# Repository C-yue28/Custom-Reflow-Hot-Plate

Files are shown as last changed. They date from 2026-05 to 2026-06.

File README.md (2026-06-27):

<h1>Custom Reflow Oven</h1>

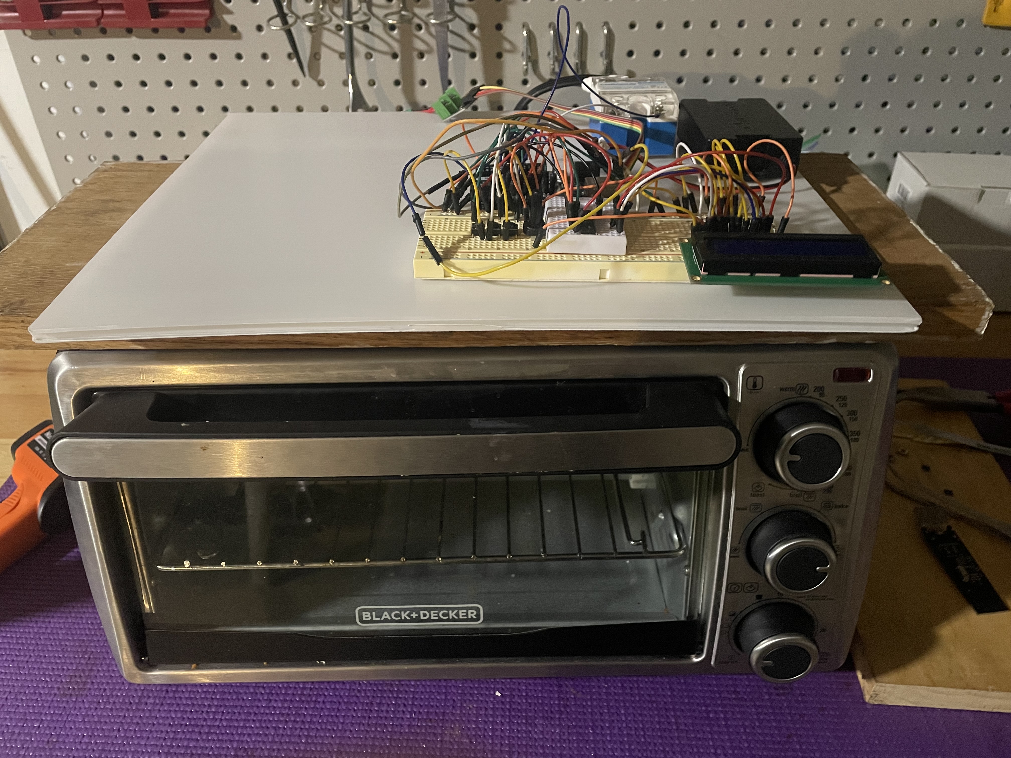
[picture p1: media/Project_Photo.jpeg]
Project Photo


<h3>Why did I make this?</h3>
<p>Designing and purchasing custom PCBs is expensive. For reference, my first custom devboard was quoted by JLCPCB at around $180, and almost 75% of that was due to assembly costs. Therefore, I sought to cut costs by designing my own at-home PCB assembly system, beginning with the "simplest" part of the process, which is being able to solder on components, both surface-mount and through-hole. This oven will be used to solder surface-mount components which would otherwise be extremely hard to solder by hand otherwise due to high pin density and small pin sizing.</p>

<h3>Why not just buy one?</h3>
<p>The cheapest reflow oven available online is around $100; additionally, this is from a site which has a questionable reputation. Since I was able to salvage some electronics components from old projects/appliances at home for the central controller, I decided to simply build my own to further reduce costs, only spending an extra $26 on a 240VAC relay and a thermocouple for precise temperature control.</p>

<h3>How does it work?</h3>
<p>Reflow soldering is a well-documented technique. Using a precise heating curve for four distinct stages, the process proceeds as follows: preheat, thermal soak, reflow, cooling. The thermocouple and the central controlling logic is necessary to maintain the correct temperature so that the solder paste on the board melts at the precise moment where it can then form a solid electrical connection between the pins of the component and the exposed copper on the board. 
<ol>
  <li>
    Preheat
  </li>
  <ul>
    <li>
      Heating rates need to be controlled during the preheat phase to prevent bubbling/splatter of the solder paste and warping of the components.
    </li>
  </ul>
  <li>
    Thermal soak
  </li>
  <ul>
    <li>
      The thermal soak phase temperature needs to be held steady to ensure even heating.    
    </li>
  </ul>
  <li>
    Reflow
  </li>
  <ul>
    <li>
      The peak temperature, achieved during reflow, needs to be tuned so that the sensitive components are not damaged while the solder paste is free to flow; due to the forces of surface tension, the paste will "pull" the pins directly over the copper on the board.
    </li>
  </ul>
  <li>
    Cooling
  </li>
  <ul>
    <li>
      Cooling needs to be gradual so that the joints are solid and no thermal shock effects occur.
    </li>
  </ul>
</ol>

<h3>Project Photo</h3>

Main Photo

<h3>BOM</h3>

| Name | Description | Need to buy? | Cost? |
|---|---|---|---|
| Arduino Uno R3 | Microcontroller unit; central "brain" of the project | No | |
| LCD1602 (16x2) | Basic display for user configuration of settings & temperature display | No | |
| 74HC595 | Digital IO expander used to control the LCD display | No | |
| Small breadboard | House all of the electronics (I may get a perfboard and solder components on later | No | |
| 10K Potentiometer | For controlling LED backlight on the LCD display | No | |
| SSR-25DA | 25A 120VAC DC-AC solid state relay for controlling heating element | Yes | 11.99 |
| MAX6675 + K-type thermocouple | Temperature sensing for PID control | Yes | 3.61  |
| 2-3 buttons | User configuration of settings | No | |
| Jumper wires | Wiring | No | |
| Toaster oven | Main heating element | No | |
| Shipping | | | 3.99  |
| Total | | | 19.59 |

<h3>Technical details</h3>

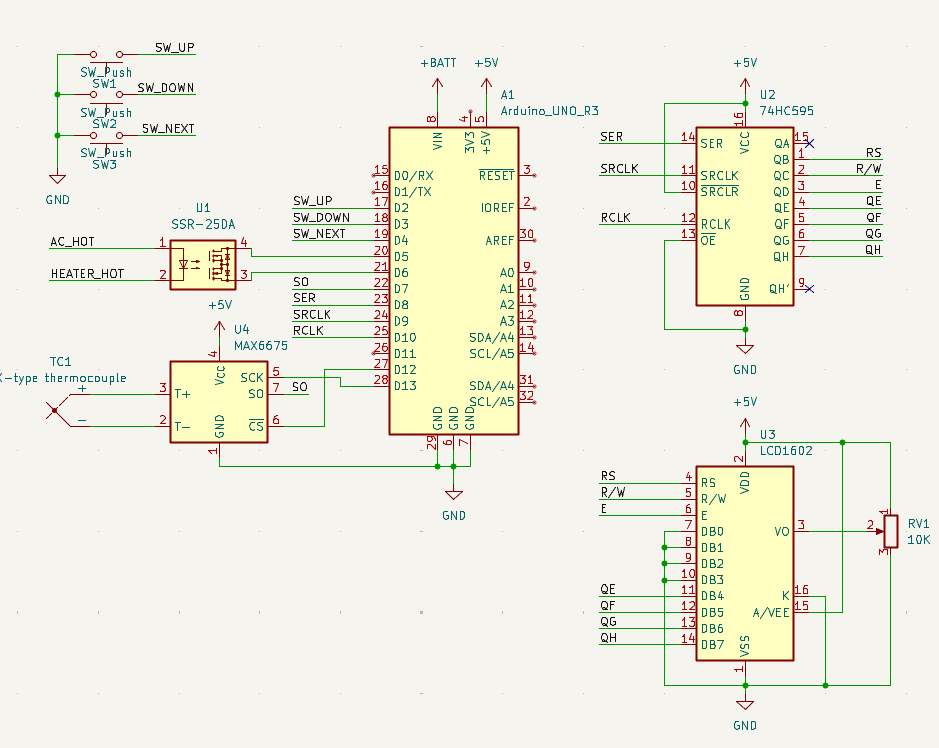
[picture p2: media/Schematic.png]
Schematic


<p>Screenshot of the schematic, which is located in the Electronics folder. The main components are the Arduino Uno (microcontroller), relay, thermocouple w/ MAX6675 module, 16x2 LCD, and 74HC595 shift register.</p>

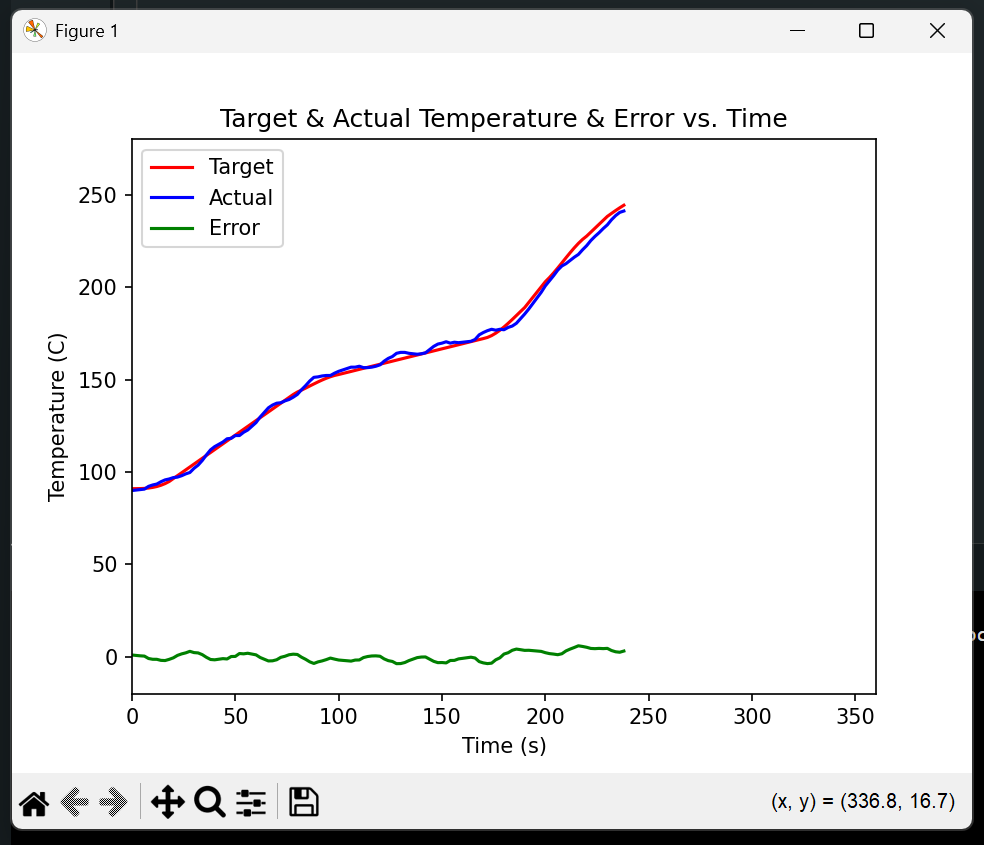
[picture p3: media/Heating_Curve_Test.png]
Heating Curve


<p>The controller uses a PD algorithm (Kp=0.05, Kd=Kp*Td=0.35) to maintain a mean absolute error of +-1.8 degrees Celsius.</p>
<p>The curve shown in this diagram follows a profile given by the datasheet for the ChipQuik NC191SNL15 lead-free solder paste. </p>

<h3>Sample testing output</h3>
<p>The example output below is directly printed out by serial and read in by data_visualization.py (located in firmware folder). The first few lines are parameters for heating curve smoothing which are calculated automatically by the software; the following lines all include time (in ms), target temperature, actual temperature, and deviation. Some lines in the middle say "Bezier," these are for debugging the smoothing parameters. Nominal heating rate is automatically calculated based on the smoothing parameters. </p>

```
0, 91.00, 91.01, 91.04, 91.14, 91.33, 91.65, 92.13, 92.79, 93.67, 94.81, 
1, 143.28, 144.32, 145.42, 146.55, 147.67, 148.77, 149.80, 150.75, 151.58, 152.27,
2, 172.22, 172.84, 173.83, 175.14, 176.71, 178.51, 180.47, 182.55, 184.70, 186.87,
3, 203.00, 205.25, 207.74, 210.41, 213.17, 215.96, 218.70, 221.31, 223.73, 225.87,
4, 238.33, 239.93, 241.49, 242.99, 244.39, 245.67, 246.78, 247.70, 248.40, 248.85, Time:10969,Target:91.17,Actual:89.50,Error:1.67
Time:12969,Target:91.00,Actual:90.00,Error:1.00
Time:14969,Target:91.01,Actual:90.25,Error:0.76
Time:16969,Target:91.05,Actual:90.50,Error:0.55
Time:18969,Target:91.15,Actual:90.75,Error:0.40
Time:20969,Target:91.35,Actual:92.25,Error:-0.90
Time:22969,Target:91.68,Actual:93.00,Error:-1.32
Time:24969,Target:92.16,Actual:93.50,Error:-1.34
Time:26969,Target:92.84,Actual:94.75,Error:-1.91
Time:28969,Target:93.74,Actual:95.75,Error:-2.01
Time:30969,Target:94.89,Actual:96.25,Error:-1.36
Time:32969,Target:96.46,Actual:97.00,Error:-0.54
Time:34969,Target:98.03,Actual:97.25,Error:0.78
Time:36969,Target:99.59,Actual:98.00,Error:1.59
Time:38969,Target:101.16,Actual:99.00,Error:2.16
Time:40969,Target:102.73,Actual:99.75,Error:2.98
Time:42969,Target:104.30,Actual:102.00,Error:2.30
Time:44969,Target:105.87,Actual:103.75,Error:2.12
Time:46969,Target:107.44,Actual:106.25,Error:1.19
Time:48969,Target:109.00,Actual:109.25,Error:-0.25
Time:50969,Target:110.57,Actual:112.00,Error:-1.43
Time:52969,Target:112.14,Actual:113.75,Error:-1.61
Time:54969,Target:113.71,Actual:115.00,Error:-1.29
Time:56969,Target:115.28,Actual:116.25,Error:-0.97
Time:58969,Target:116.85,Actual:118.00,Error:-1.15
Time:60969,Target:118.42,Actual:118.25,Error:0.17
Time:62969,Target:119.98,Actual:119.75,Error:0.23
Time:64969,Target:121.55,Actual:119.75,Error:1.80
Time:66969,Target:123.12,Actual:121.50,Error:1.62
Time:68969,Target:124.69,Actual:122.75,Error:1.94
Time:70969,Target:126.26,Actual:124.75,Error:1.51
Time:72969,Target:127.83,Actual:126.75,Error:1.08
Time:74969,Target:129.40,Actual:129.75,Error:-0.35
Time:76969,Target:130.96,Actual:132.25,Error:-1.29
Time:78969,Target:132.53,Actual:134.75,Error:-2.22
Time:80969,Target:134.10,Actual:136.25,Error:-2.15
Time:82969,Target:135.67,Actual:137.25,Error:-1.58
Time:84969,Target:137.24,Actual:137.50,Error:-0.26
Time:86969,Target:138.81,Actual:138.50,Error:0.31
Time:88969,Target:140.38,Actual:139.25,Error:1.13
Time:90969,Target:141.94,Actual:140.50,Error:1.44
Bezier smoothing post 0.00
Time:92969,Target:143.28,Actual:142.00,Error:1.28
Bezier smoothing post 0.10
Time:94969,Target:144.32,Actual:144.50,Error:-0.18
Bezier smoothing post 0.20
Time:96969,Target:145.42,Actual:146.75,Error:-1.33
Bezier smoothing post 0.30
Time:98969,Target:146.55,Actual:149.25,Error:-2.70
Bezier smoothing post 0.40
Time:100969,Target:147.67,Actual:151.25,Error:-3.58
Nominal rate 0.28
Bezier smoothing pre 0.50
Time:102969,Target:148.77,Actual:151.50,Error:-2.73
Bezier smoothing pre 0.60
Time:104969,Target:149.80,Actual:152.00,Error:-2.20
Bezier smoothing pre 0.70
Time:106969,Target:150.75,Actual:152.25,Error:-1.50
Bezier smoothing pre 0.80
Time:108969,Target:151.58,Actual:152.25,Error:-0.67
Bezier smoothing pre 0.90
Time:110969,Target:152.27,Actual:153.50,Error:-1.23
Bezier smoothing pre 1.00
Time:112969,Target:152.78,Actual:154.50,Error:-1.72
Time:114969,Target:153.33,Actual:155.25,Error:-1.92
Time:116969,Target:153.89,Actual:156.00,Error:-2.11
Time:118969,Target:154.44,Actual:156.75,Error:-2.31
Time:120969,Target:155.00,Actual:156.75,Error:-1.75
Time:122969,Target:155.56,Actual:157.25,Error:-1.69
Time:124969,Target:156.11,Actual:156.50,Error:-0.39
Time:126969,Target:156.67,Actual:156.50,Error:0.17
Time:128969,Target:157.22,Actual:156.75,Error:0.47
Time:130969,Target:157.78,Actual:157.25,Error:0.53
Time:132969,Target:158.33,Actual:158.00,Error:0.33
Time:134969,Target:158.89,Actual:160.00,Error:-1.11
Time:136969,Target:159.44,Actual:161.50,Error:-2.06
Time:138969,Target:160.00,Actual:162.50,Error:-2.50
Time:140969,Target:160.56,Actual:164.25,Error:-3.69
Time:142969,Target:161.11,Actual:164.75,Error:-3.64
Time:144969,Target:161.67,Actual:164.75,Error:-3.08
Time:146969,Target:162.22,Actual:164.25,Error:-2.03
Time:148969,Target:162.78,Actual:164.00,Error:-1.22
Time:150969,Target:163.33,Actual:163.75,Error:-0.42
Time:152969,Target:163.89,Actual:164.00,Error:-0.11
Time:154969,Target:164.44,Actual:164.50,Error:-0.06
Time:156969,Target:165.00,Actual:166.25,Error:-1.25
Time:158969,Target:165.56,Actual:168.00,Error:-2.44
Time:160969,Target:166.11,Actual:169.25,Error:-3.14
Time:162969,Target:166.67,Actual:169.75,Error:-3.08
Time:164969,Target:167.22,Actual:170.50,Error:-3.28
Time:166969,Target:167.78,Actual:169.75,Error:-1.97
Time:168969,Target:168.33,Actual:170.25,Error:-1.92
Time:170969,Target:168.89,Actual:170.00,Error:-1.11
Time:172969,Target:169.44,Actual:170.25,Error:-0.81
Time:174969,Target:170.00,Actual:170.50,Error:-0.50
Time:176969,Target:170.56,Actual:170.75,Error:-0.19
Time:178969,Target:171.11,Actual:171.75,Error:-0.64
Time:180969,Target:171.67,Actual:174.25,Error:-2.58
Bezier smoothing post 0.00
Time:182969,Target:172.22,Actual:175.50,Error:-3.28
Bezier smoothing post 0.10
Time:184969,Target:172.84,Actual:176.50,Error:-3.66
Bezier smoothing post 0.20
Time:186969,Target:173.83,Actual:177.25,Error:-3.42
Bezier smoothing post 0.30
Time:188969,Target:175.14,Actual:176.75,Error:-1.61
Bezier smoothing post 0.40
Time:190969,Target:176.71,Actual:177.25,Error:-0.54
Nominal rate 1.40
Bezier smoothing pre 0.50
Time:192969,Target:178.51,Actual:177.00,Error:1.51
Bezier smoothing pre 0.60
Time:194969,Target:180.47,Actual:178.25,Error:2.22
Bezier smoothing pre 0.70
Time:196969,Target:182.55,Actual:179.00,Error:3.55
Bezier smoothing pre 0.80
Time:198969,Target:184.70,Actual:180.50,Error:4.20
Bezier smoothing pre 0.90
Time:200969,Target:186.87,Actual:183.00,Error:3.87
Bezier smoothing pre 1.00
Time:202969,Target:189.00,Actual:185.50,Error:3.50
Time:204969,Target:191.80,Actual:188.25,Error:3.55
Time:206969,Target:194.60,Actual:191.25,Error:3.35
Time:208969,Target:197.40,Actual:194.25,Error:3.15
Time:210969,Target:200.20,Actual:197.25,Error:2.95
Bezier smoothing post 0.00
Time:212969,Target:203.00,Actual:200.75,Error:2.25
Bezier smoothing post 0.10
Time:214969,Target:205.25,Actual:203.50,Error:1.75
Bezier smoothing post 0.20
Time:216969,Target:207.74,Actual:206.25,Error:1.49
Bezier smoothing post 0.30
Time:218969,Target:210.41,Actual:209.25,Error:1.16
Bezier smoothing post 0.40
Time:220969,Target:213.17,Actual:211.50,Error:1.67
Nominal rate 1.07
Bezier smoothing pre 0.50
Time:222969,Target:215.96,Actual:212.75,Error:3.21
Bezier smoothing pre 0.60
Time:224969,Target:218.70,Actual:214.50,Error:4.20
Bezier smoothing pre 0.70
Time:226969,Target:221.31,Actual:216.25,Error:5.06
Bezier smoothing pre 0.80
Time:228969,Target:223.73,Actual:217.75,Error:5.98
Bezier smoothing pre 0.90
Time:230969,Target:225.87,Actual:220.25,Error:5.62
Bezier smoothing pre 1.00
Time:232969,Target:227.67,Actual:222.50,Error:5.17
Time:234969,Target:229.80,Actual:225.25,Error:4.55
Time:236969,Target:231.93,Actual:227.50,Error:4.43
Time:238969,Target:234.07,Actual:229.50,Error:4.57
Time:240969,Target:236.20,Actual:231.75,Error:4.45
Bezier smoothing post 0.00
Time:242969,Target:238.33,Actual:233.75,Error:4.58
Bezier smoothing post 0.10
Time:244969,Target:239.93,Actual:236.50,Error:3.43
Bezier smoothing post 0.20
Time:246969,Target:241.49,Actual:238.75,Error:2.74
Bezier smoothing post 0.30
Time:248969,Target:242.99,Actual:240.50,Error:2.49
Bezier smoothing post 0.40
Time:250969,Target:244.39,Actual:241.25,Error:3.14
Nominal rate -0.00
```

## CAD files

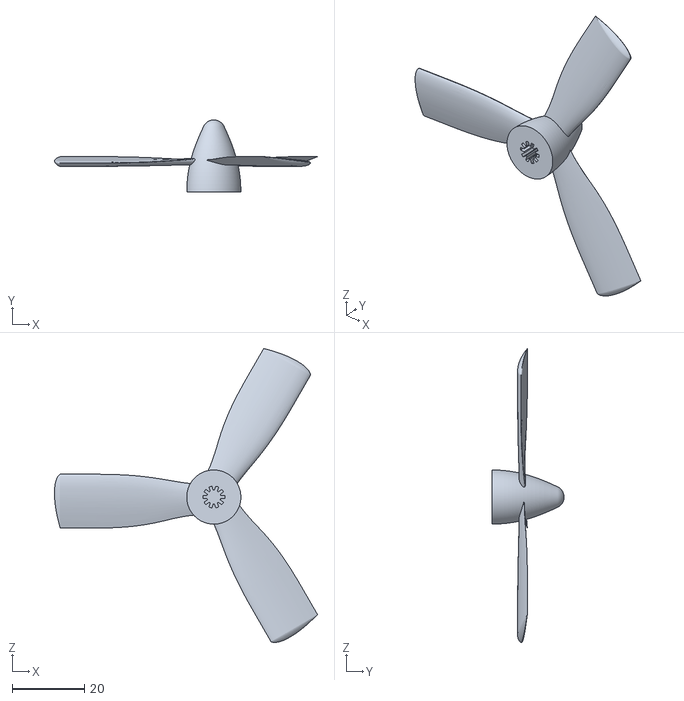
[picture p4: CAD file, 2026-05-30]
CAD/Propeller Assembly.stl
72.9 x 20.0 x 81.5

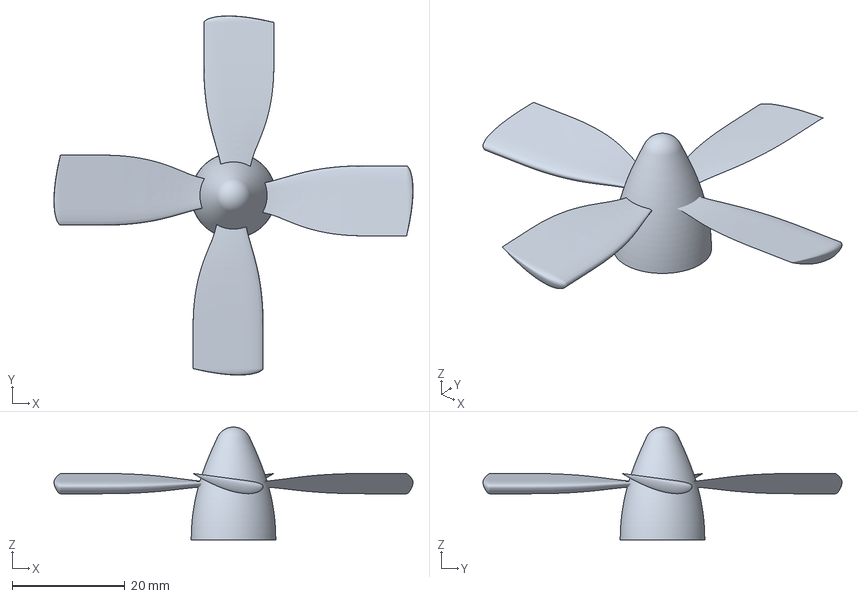
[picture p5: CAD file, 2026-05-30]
CAD/Fan Propeller.3mf
63.6 x 63.6 x 20.0 mm

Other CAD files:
CAD/Fan Propeller.stl

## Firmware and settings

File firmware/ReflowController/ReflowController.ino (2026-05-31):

#include "MAX6675.h"
#include "ReflowGUI.h" 

/*

Reflow Hot Plate Firmware
Written by Christopher Yue

*/

// PIN DESIGNATION
#define SW_UP 2
#define SW_DOWN 3
#define SW_NEXT 4
#define RELAY_N 5
#define RELAY_P 6
#define SERIAL_INPUT 7 // SO pin of MAX6675
#define SERIAL_OUT 8 // SER pin of 74HC595
#define SRCLK 9 // shift register clock 74HC595
#define RCLK 10 // register clock 74HC595
#define CHIP_SELECT 12 // CS pin MAX6675
#define SERIAL_CLOCK 13 // SCK pin MAX6675

// #define MOTOR_EN 5
// #define MOTOR_A A2
// #define MOTOR_B A1

// PARAMETERS
// default HEATING_PARAMETERS
// tuned for ChipQuik NC191SNL15 solder paste
#define PREHEAT_TEMP 150.0
#define PREHEAT_DURATION 90.0
#define SOAK_TEMP 175.0
#define SOAK_DURATION 90.0
#define MELTING_POINT 217.0
#define RAMP_DURATION 30.0
#define REFLOW_TEMP 249.0
#define REFLOW_DURATION 60.0

#define PWM_PERIOD 2000 // ms

// PID - zieger-nichols method
#define KP 0.05
#define TD 7
// not needed - can simply use standard form of PID equation
// #define KI KP/TI
// #define KD KP*TD

#define PREHEAT 0
#define SOAK 2
#define MELT 4
#define REFLOW 6

#define HEATING_BUFFER_THRESHOLD 1.5
#define CURVE_CONSTANT 10.0

float HEATING_PARAMETERS[8] = {PREHEAT_TEMP, PREHEAT_DURATION, SOAK_TEMP, SOAK_DURATION, MELTING_POINT, RAMP_DURATION, REFLOW_TEMP, REFLOW_DURATION};
const float INCREMENTS[8] = {2.5, 5, 2.5, 5, 2.5, 5, 2.5, 5};
float HEATING_RATES[4] = {PREHEAT_TEMP/PREHEAT_DURATION, (SOAK_TEMP-PREHEAT_TEMP)/SOAK_DURATION, (MELTING_POINT-SOAK_TEMP)/RAMP_DURATION, (REFLOW_TEMP-MELTING_POINT)/(REFLOW_DURATION/2)};

struct Point {
    float x;
    float y;
};

// Bezier smoothing algorithm, sourced mainly using AI
class BezierCorner {
  private:
    Point p0, p1, p2, p3;

    float formula(float coord0, float coord1, float coord2, float coord3, float t) {
        float u = 1.0 - t;
        return (u*u*u * coord0) + (3.0 * u*u * t * coord1) + (3.0 * u * t*t * coord2) + (t*t*t * coord3);
    }

  public:
    void setup(Point start, Point ctrl1, Point ctrl2, Point end) {
        p0 = start; p1 = ctrl1; p2 = ctrl2; p3 = end;
    }

    float getTemperatureAtTime(float t) { // as a decimal between 0.0 and 1.0
      return formula(p0.y, p1.y, p2.y, p3.y, t);
    }
};

BezierCorner smoothCorners[5];

MAX6675 thermocouple(SERIAL_CLOCK, CHIP_SELECT, SERIAL_INPUT);
LCD1602 display(SRCLK, RCLK, SERIAL_OUT); // controlled using 74HC595, RS is B, R/W is C, E is D, data pins 4-7 correspond to E-H
ReflowGUI gui(display);

bool HEATING = false;
bool STATE_SW_NEXT = false;

bool hasAdvanced = false;
bool check_gui = true;
volatile bool hasEdited = false;
bool heating_buffer_active = false; 

long time;
long START;
long prevButtonCheckTime = 0;
long prevCycleTime = 0;
float heating_start_time = -1;
float heating_duration = -1.0;
float nominal_heating_rate = 0.0;

int phase = PREHEAT; // preheat, soak, reflow, cool
float targetTemp;
float temp;
float prevError = 0;

float DUTY_CYCLE;
float ie;

// bool hasIncremented = false;
// bool hasIncremented = false;

float updateHeatingRates() {
  HEATING_RATES[0] = (HEATING_PARAMETERS[PREHEAT]-temp)/HEATING_PARAMETERS[1];
  for (int i = SOAK; i < REFLOW; i+=2) {
    HEATING_RATES[(int)i/2] = (float)(HEATING_PARAMETERS[i] - HEATING_PARAMETERS[i-2]) / HEATING_PARAMETERS[i+1];
  }
  HEATING_RATES[(int)REFLOW/2] = (float)(HEATING_PARAMETERS[REFLOW] - HEATING_PARAMETERS[MELT]) / (HEATING_PARAMETERS[REFLOW+1]/2);
}

void incrementValue() {
  if (!digitalRead(SW_UP)) {
    if (!hasEdited) {
      HEATING_PARAMETERS[gui.screen]+=INCREMENTS[gui.screen];
      gui.edit_param(HEATING_PARAMETERS[gui.screen]);
      hasEdited = true;
    }
  } else {
    hasEdited = false;
  }
  delay(50);
}

void decrementValue() {
  if (!digitalRead(SW_DOWN)) {
    if (!hasEdited) {
      HEATING_PARAMETERS[gui.screen]-=INCREMENTS[gui.screen];
      gui.edit_param(HEATING_PARAMETERS[gui.screen]);
      hasEdited = true;
    }
  } else {
    hasEdited = false;
  }
  delay(50);
}

void nextValue() {
  if (gui.advance_screen(gui.screen >= 7 ? NULL : HEATING_PARAMETERS[gui.screen+1])) {
    temp = thermocouple.readData();
    start();
    return;
  }
  delay(50);
}

void setupCornerSmoothing() {

  // 0: start to preheat
  // 1: preheat to soak
  // 2: soak to melt
  // 3: melt to reflow
  // 4: reflow to cool


  smoothCorners[0].setup(
    {0, temp+HEATING_BUFFER_THRESHOLD},
    {CURVE_CONSTANT/2, temp+HEATING_BUFFER_THRESHOLD},
    {CURVE_CONSTANT/2, temp+HEATING_BUFFER_THRESHOLD},
    {CURVE_CONSTANT, temp+CURVE_CONSTANT*HEATING_RATES[0]}
  );

  smoothCorners[4].setup(
    {-CURVE_CONSTANT, HEATING_PARAMETERS[REFLOW] - CURVE_CONSTANT*HEATING_RATES[3]},
    {-CURVE_CONSTANT/2, HEATING_PARAMETERS[REFLOW] - (CURVE_CONSTANT/2)*HEATING_RATES[3]},
    {-CURVE_CONSTANT/2, HEATING_PARAMETERS[REFLOW]},
    {0, HEATING_PARAMETERS[REFLOW]}
  );

  for (int i = 1; i < 4; i++) {
    // soak -> melt -> reflow
    smoothCorners[i].setup(
      {-CURVE_CONSTANT, HEATING_PARAMETERS[2*(i-1)]-CURVE_CONSTANT*HEATING_RATES[i-1]},
      {-CURVE_CONSTANT/2, HEATING_PARAMETERS[2*(i-1)]-(CURVE_CONSTANT/2)*HEATING_RATES[i-1]},
      {CURVE_CONSTANT/2, HEATING_PARAMETERS[2*(i-1)]+(CURVE_CONSTANT/2)*HEATING_RATES[i]},
      {CURVE_CONSTANT, HEATING_PARAMETERS[2*(i-1)]+CURVE_CONSTANT*HEATING_RATES[i]}
    );
  }

  for (int i = 0; i < 5; i++) {
    Serial.print(i);
    Serial.print(", ");
    for (float j = 0.0; j <= 1.0; j+=0.1) {
      Serial.print(smoothCorners[i].getTemperatureAtTime(j));
      Serial.print(", ");
    }
    Serial.println();
  }

}

float getTargetTempAt(long elapsedTimeInPhase, int phase, long duration) {
  if (phase == PREHEAT && elapsedTimeInPhase <= CURVE_CONSTANT*2000) {
    return smoothCorners[(int)phase/2].getTemperatureAtTime(elapsedTimeInPhase/(2*CURVE_CONSTANT*1000));
  }
  if (elapsedTimeInPhase <= CURVE_CONSTANT*1000) {
    float t = min(1.0, elapsedTimeInPhase/(2*CURVE_CONSTANT*1000)+0.5);
    t = round(t*CURVE_CONSTANT)/CURVE_CONSTANT;
    Serial.print("Bezier smoothing pre ");
    Serial.println(t);
    return smoothCorners[(int)phase/2].getTemperatureAtTime(t);
  } else if (elapsedTimeInPhase >= (duration-CURVE_CONSTANT)*1000) {
    float t = (elapsedTimeInPhase/1000.0+CURVE_CONSTANT-duration)/(2*CURVE_CONSTANT);
    t = round(t*CURVE_CONSTANT)/CURVE_CONSTANT;
    Serial.print("Bezier smoothing post ");
    Serial.println(t);
    return smoothCorners[((int)phase/2)+1].getTemperatureAtTime(t);
  }
  return -1;
}

void start() {
  detachInterrupt(digitalPinToInterrupt(SW_UP));
  detachInterrupt(digitalPinToInterrupt(SW_DOWN));

  HEATING = true;
  check_gui = false;
  DUTY_CYCLE = 0.5;
  heating_start_time = time;
  heating_duration = HEATING_PARAMETERS[1];
  phase = PREHEAT;

  temp = thermocouple.readData();
  targetTemp = temp + HEATING_RATES[0];

  updateHeatingRates();
  setupCornerSmoothing();

  nominal_heating_rate = (smoothCorners[1].getTemperatureAtTime(0.0) - smoothCorners[0].getTemperatureAtTime(1.0))/(HEATING_PARAMETERS[1]-3*CURVE_CONSTANT);

  gui.printHeating(phase);
}

float cmap(float val, float olow, float ohigh, float mlow, float mhigh) {
  return constrain(map(val, olow, ohigh, mlow, mhigh), mlow, mhigh);
}

// void motorSpeed(float val) {
//   int map_speed = cmap(abs(val), 0, 100, 0, 255);

//   if (val > 0) {
//     digitalWrite(MOTOR_A, HIGH);
//     digitalWrite(MOTOR_B, LOW);
//   }
//   else {
//     digitalWrite(MOTOR_A, LOW);
//     digitalWrite(MOTOR_B, HIGH);
//   }

//   analogWrite(MOTOR_EN, map_speed);
// }

void reset() {
  phase=PREHEAT;
  HEATING = false;
  gui.screen = 0;
  gui.update(HEATING_PARAMETERS[0]);
  check_gui = true;
  attachInterrupt(digitalPinToInterrupt(SW_UP), incrementValue, CHANGE);
  attachInterrupt(digitalPinToInterrupt(SW_DOWN), decrementValue, CHANGE);
  digitalWrite(RELAY_P, LOW);
  heating_buffer_active = true;
  //motorSpeed(0);
}

void updateHeating() {

  if (time - prevCycleTime >= DUTY_CYCLE*PWM_PERIOD) {
    digitalWrite(RELAY_P, LOW);
  }

  if (time - prevCycleTime >= PWM_PERIOD) {

    // end of a period

    // PID implementation

    // first check how much we are off by - positive means too low, negative means too high
    float error = targetTemp-temp; // C
    float de = (error-prevError); // C/s, if error is increasing this is positive meaning that we need to heat faster, if error is decreasing this is negative meaning we need to heat slower
    ie += (error+prevError/2); // rough estimation, we can consider each new point as adding a triangle and a rectangle

    DUTY_CYCLE += KP*(error+TD*de);
    if (DUTY_CYCLE < 0) DUTY_CYCLE = 0;
    else if (DUTY_CYCLE > 1) DUTY_CYCLE = 1;

    // print data
    Serial.print("Time:");
    Serial.print(time);
    Serial.print(",");
    Serial.print("Target:");
    Serial.print(targetTemp);
    Serial.print(",");
    Serial.print("Actual:"); 
    Serial.print(temp);
    Serial.print(",");
    Serial.print("Error:");
    Serial.println(error);
    
    if (time-heating_start_time >= heating_duration*1000) {
      phase+=2;
      heating_start_time = time;
      heating_duration = phase == REFLOW ? HEATING_PARAMETERS[phase+1]/2 : HEATING_PARAMETERS[phase+1];

      float t_next = smoothCorners[(int)phase/2+1].getTemperatureAtTime(0.0);
      float t_start = smoothCorners[(int)phase/2].getTemperatureAtTime(1.0);

      nominal_heating_rate = heating_duration-CURVE_CONSTANT*2 <= 0.25 ? 0.0 : (t_next-t_start)/(heating_duration-CURVE_CONSTANT*2);
      Serial.print("Nominal rate ");
      Serial.println(nominal_heating_rate);
      if (phase > REFLOW) {
        reset();
        return;
      }
    }

    float targetTemp_temp = targetTemp;
    targetTemp = getTargetTempAt(time-heating_start_time, phase, heating_duration);
    
    if (targetTemp + 1 <= 0.05) { // floating point issues
      targetTemp = min(targetTemp_temp + nominal_heating_rate * (PWM_PERIOD/1000), HEATING_PARAMETERS[phase]);
    }

    if (DUTY_CYCLE > 0) {
      digitalWrite(RELAY_P, HIGH);
    } else {
      digitalWrite(RELAY_P, LOW);
    }
    prevCycleTime = time;
    prevError = error;

  }
}

void setup() {

  Serial.begin(115200);
  delay(1000);

  pinMode(SW_UP, INPUT_PULLUP);
  pinMode(SW_DOWN, INPUT_PULLUP);
  pinMode(SW_NEXT, INPUT_PULLUP);

  pinMode(RELAY_P, OUTPUT);
  pinMode(RELAY_N, OUTPUT);

  // pinMode(MOTOR_EN, OUTPUT);
  // pinMode(MOTOR_A, OUTPUT);
  // pinMode(MOTOR_B, OUTPUT);

  digitalWrite(RELAY_P, LOW);
  digitalWrite(RELAY_N, LOW);

  delay(500);

  attachInterrupt(digitalPinToInterrupt(SW_UP), incrementValue, CHANGE);
  attachInterrupt(digitalPinToInterrupt(SW_DOWN), decrementValue, CHANGE);

  display.begin();
  display.print("Ready.");

  delay(500);

  gui.update(HEATING_PARAMETERS[gui.screen]);
  //motorSpeed(0);

}

void loop() {
  bool state = digitalRead(SW_NEXT);
  time = millis();

  if (time - prevButtonCheckTime >= 10) {
    if (check_gui) {
      if (!state && STATE_SW_NEXT) {
        if (!hasAdvanced) {
          nextValue();
          hasAdvanced = true;
        }
      } else if (state && !STATE_SW_NEXT) {
        hasAdvanced = false;
      }
    } else if (!state && STATE_SW_NEXT) {
      // reset when next button is pressed while heating is going on
      // must hold for at least a second to stop
      delay(1000);
      if (!digitalRead(SW_NEXT)) {
        reset();
      }
    }

    STATE_SW_NEXT = state;
    prevButtonCheckTime = time;
  }

  time = millis();

  if (HEATING) {
    if (time % 250 <= 25) {
      temp = thermocouple.readData();
    }
    if (time % 1000 <= 25) {
      if (time % 2000 <= 25) {
        gui.printTemperatureWhileHeating(temp, phase/2);
      } else {
        gui.printHeating(phase/2);
      }
    }
    updateHeating();
  }
}

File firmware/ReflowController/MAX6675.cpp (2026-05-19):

#include "MAX6675.h"
#include <Arduino.h>

MAX6675::MAX6675(int _SCK, int _CS, int _SO) {
  SCK = _SCK;
  CS = _CS;
  SO = _SO;

  pinMode(SCK, OUTPUT);
  pinMode(CS, OUTPUT);
  pinMode(SO, INPUT);

  digitalWrite(CS, HIGH);
  digitalWrite(SCK, LOW);
}

float MAX6675::readData() {
  digitalWrite(CS, LOW);
  delayMicroseconds(1); // minimum 100 ns = 0.1 us + some tolerance
  int data = 0;
  
  // timing:
  // SCK fall to output data valid max 100 ns = 0.1 us, I'm just going to round it up to one microsecond, can't hurt

  for (int i = 0; i < 16; i++) {
    digitalWrite(SCK, HIGH);
    delayMicroseconds(1);

    data |= digitalRead(SO) << (15-i);
    
    digitalWrite(SCK, LOW);
    delayMicroseconds(1);
  }
  digitalWrite(CS, HIGH);

  // bit 0 is useless, bit 1 is useless, bit 2 is thermocouple checker, bit 15 is useless

  if (data & 4) return -1;
  return (float)((data >> 3) & 4095)/4;
  

}

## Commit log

2026-05-13 Commit all current CAD files, electronics diagrams, and firmware
2026-05-13 Commit all CAD files, electronics diagrams, and initial firmware
    [Electronics BOM.csv, Reflow Hot Plate Schematic.kicad_sch]
2026-05-18 Updated temperature sensing
    [Reflow Hot Plate Schematic.kicad_sch]
2026-05-19 Added full GUI and editability of heating parameters
    [Reflow Hot Plate Schematic.kicad_sch]
2026-05-30 Data visualization implemented, smoothed heating curve, implemented heating stages, did preliminary tuning
    [(obsolete) Fan Propeller.stl, Fan Propeller.3mf, Fan Propeller.stl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]
2026-05-30 Added visual studio files to gitignore
    [(obsolete) Fan Propeller.stl, Electronics BOM.csv, Fan Propeller.3mf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]
2026-05-31 PID tuning and heating curve smoothing complete
    [(obsolete) (new) Fan Propeller.stl, (obsolete) Fan Propeller.3mf, (obsolete) Propeller Assembly.stl]
2026-06-02 Update BOM
    [BOM.csv, Electronics BOM.csv]
2026-06-02 Screenshot schematic
    [Reflow Hot Plate Schematic.kicad_sch]
2026-06-02 Create main assembly with all electronics and CAD
2026-06-16 Remove obsolete files
    [(obsolete) (new) Fan Propeller.stl, (obsolete) Fan Propeller.3mf, (obsolete) Fan Propeller.stl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]
